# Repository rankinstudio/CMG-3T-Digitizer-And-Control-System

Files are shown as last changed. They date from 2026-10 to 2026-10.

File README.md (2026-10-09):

# CMG-3T Digitizer And Control System

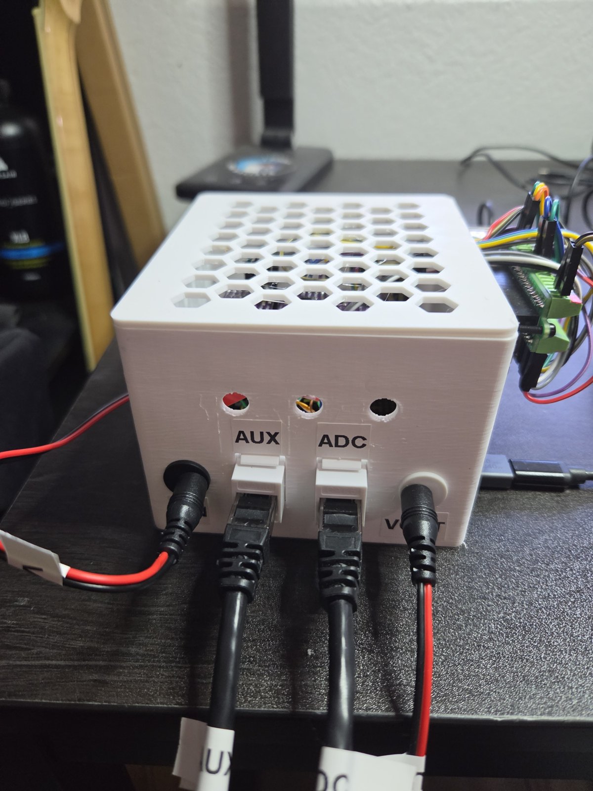
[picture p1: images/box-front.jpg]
The board box: VIN, AUX, ADC and VOUT on the front, the Pi on its side


A three-component digitizer for a Güralp CMG-3T 120 s broadband seismometer:
three ADS1220s for velocity and an ADS1115 for the mass positions, on two
ElectroCookie solderable breadboards, read by a Raspberry Pi 5 that also
locks, unlocks and centres the masses. 0.489 nm/s per count, ±4.1 mm/s full
scale, ~1.5 nm/s/√Hz floor, 100 SPS miniSEED.

**`cmg3t-digitizer.html`** is the build document: block diagram, parts list
with DigiKey numbers, both board layouts hole by hole, the sensor cable table,
the Pi wiring, and the assembly and test stages.
**[Read it here](https://rankinstudio.github.io/CMG-3T-Digitizer-And-Control-System/cmg3t-digitizer.html)** (GitHub's file view shows only
the source).

Companion project: [DIY-SEISMO](https://github.com/rankinstudio/DIY-SEISMO), a
geophone station built the same way; the shared stream format and capture core
come from it.

| Path | What |
|---|---|
| `cmg3t-digitizer.html` | Build document |
| `connector_pinface.png` | The sensor's 26-pin connector, pin letters from the pin face |
| `pi/` | Pi software: capture daemon, mass control, bring-up checks ([README](pi/README.md)) |
| `enclosure/` | 3D-printed box for the boards with the Pi on its side ([README](enclosure/README.md)) |
| `pc/` | PC viewer (Z/N/E traces and spectrograms in three bands) and earthquake plots ([README](pc/README.md)) |

## About the sensor

**History.** Güralp Systems, of Reading in England, launched the 3T in the
mid-1980s: the company dates it to 1985, and it has been in continuous
production since 1987. It was the first field-worthy three-component broadband
feedback seismometer, and more than 3000 have been deployed worldwide. It
became a standard sensor for national seismic networks and for the
instrument pools that lend seismometers to university experiments, above all
the US PASSCAL pool, which also bought cold-rated 3Ts for Antarctica. From 2004
it was one of the three broadband sensors of EarthScope's USArray
Transportable Array, alongside the Streckeisen STS-2 and the Nanometrics
Trillium 240: a grid of about 400 stations, 70 km apart, that rolled across
the lower 48 states from 2004 to 2015 (1679 sites in all), then Alaska and
western Canada until 2021.

**Retirement.** The Transportable Array closed in 2021 and the pools now field
newer designs, so many older 3Ts, typically 1990s and 2000s builds, have been
retired and turn up on the surplus market, usually without their cables. This
one, serial T35286, is ex-PASSCAL: pier tests at the instrument center in
Socorro from 2008, deployments in South Carolina (2013–2014) and at Tok in
interior Alaska (2016–2018, 26 months), and a last pier test in October 2018.
Its Alaska data, which are public, show all three components healthy at both
ends of that deployment and the centring motors still working ten weeks before
it came out.

**Performance.** Force feedback holds the masses still and reads the force
needed to do it, so one instrument covers the whole seismic band with a single
transfer function:

| | |
|---|---|
| Response | Flat to velocity, 120 s – 50 Hz (360 s and other corners were options) |
| Sensitivity | 2 × 750 V/(m/s), differential |
| Clip | ±10 V per side, ±20 V differential: about 13 mm/s |
| Self-noise | Below the USGS New Low Noise Model from beyond 200 s to 20 Hz (vertical) |
| Dynamic range | Over 140 dB across the passband; linearity >111 dB vertical, >107 dB horizontal |
| Mass control | Remote lock, unlock and centre; masses recentre over ±2.5° of tilt |
| Power | 10–36 V DC, ~62–75 mA at 12 V, more while the motors run |

In practice that range spans the Earth's quietest ground motion at long
periods, the ocean microseism at 3–20 s, the surface waves of distant
earthquakes at 20–100 s and more, and local events up to about 13 mm/s. The
vertical is the quiet component at long period; the horizontals also respond
to tilt, so in a shallow or thermally unstable vault they sit well above the
vertical below ~20 s. This digitizer clips at ±4.1 mm/s and its own floor,
~1.5 nm/s/√Hz, is below the low-noise model from 0.01 to ~0.7 Hz: the band where
the sensor is quietest.

Sources: Güralp, [About us](https://www.guralp.com/about-us) and
[CMG-3T datasheet](https://nappe.wustl.edu/SPREE/instrument-other-documentation/from-Guralp/CMG-3T-datasheet.pdf);
EarthScope Primary Instrument Center, [polar sensors](https://epic.earthscope.org/content/polar/equipment/year-round/sensors)
and [sensor comparison](https://epic.earthscope.org/content/instrumentation/sensors/sensor-comparison-chart);
USArray, [when and where](http://www.usarray.org/public/about/when) and
[the Alaska Transportable Array](http://www.usarray.org/Alaska); the unit's
history from PASSCAL station metadata (EarthScope FDSN web services) and its
TOK4 waveforms.

## Cost

Approximate, in US dollars, before shipping and tax. Part numbers are in the
build document's parts list.

| Item | Where | Cost |
|---|---|---|
| Güralp CMG-3T 120 s, used ex-pool unit (no cable) | eBay / surplus | $160 |
| Raspberry Pi 5 (4 GB), 27 W USB-C supply, active cooler, 32 GB microSD, right-angle USB-C adapter | any Pi reseller | $97 |
| ADS1220 modules ×3 (plus a spare), ADS1115 breakout | AliExpress / Amazon | $33 |
| ElectroCookie solderable breadboards (pack of 3) | Amazon | $10 |
| Board parts: 0.1 % divider resistors, film and ceramic caps, LM4040 reference, sockets, optocouplers, Schottky, 1 % resistors | DigiKey | $28 |
| Cat6 keystone jacks ×2, stranded patch cables ×2, two-core power lead, Dupont leads | Amazon | $30 |
| Panel DC jacks ×2 and a plug, panel buttons ×3, standoffs and nuts | Amazon | $20 |
| 12 V 1 A DC adapter | Amazon | $8 |
| Filament for the box (~130 g) | — | $3 |
| **Total** | | **≈ $390** |

Without the sensor it is about $230; with a Pi already on hand, about $130.
The sensor dominates, and used 3T prices vary: check a unit's history before
buying (its serial number in public station metadata).

## Skills required

None of it is advanced, but all of it gets used:

- **Through-hole soldering** on a solderable breadboard: 37 parts and about 34
  insulated jumpers and bus wires across two boards, header strips cut to length, short
  wires soldered straight into holes. A fine tip and a steady hand; no
  surface-mount work (the converters come on modules).
- **A multimeter**: resistance (telling 4.99 k from 10 k 0.1% parts before
  they go in, cold checks for shorts), DC volts (supply rails, the 2.5 V
  reference, the 12 V path) and continuity, to buzz out every conductor of the
  sensor harness. The build document names the mode and range for each step.
- **Wiring and cabling**: Dupont sockets on the sensor's pins, punching down
  Cat6 keystone jacks to T568B with a punch-down tool, panel DC jacks.
- **3D printing**: three parts with no supports. Expect to tune two clearances
  for your printer (the lid fit and its snap bumps); the fit-test plate checks
  the wall openings first.
- **Raspberry Pi and Linux**: flash Raspberry Pi OS, work over SSH, edit
  `/boot/firmware/cmdline.txt`, set up a Python venv and a systemd service.
- **Python on a PC**: install packages with pip, run scripts from a terminal,
  edit a JSON settings file.
- **Handling the sensor**: it weighs 14 kg and has locked masses. Level it with
  its feet and bubble, and lock it before it is ever moved.

Tools: soldering iron and solder, flush cutters, wire strippers, multimeter,
punch-down tool, 3D printer, a small nut driver or pliers for the standoff nuts.

## Order of work

1. Build and test the ADC board, then the AUX board (build document, stages 1–2).
2. Print the fit test, then the box; fit the boards and the Pi (stage 3).
3. Pi: Raspberry Pi OS, `pcie_aspm=off`, the capture service (`pi/README.md`).
4. Sensor: harness buzzed out, connect it locked, power, unlock on its final
   pad (stage 4). Allow ~4 hours of settling.

## Earthquake plots on the PC

`watch_cmg.py` polls the USGS catalogue for M > 4 quakes, waits until their
waves have reached the Pi's disk, and runs `cmgevent.py <usgs id>`, which saves
Z/N/E plots in the viewer's three bands (0.5–2 Hz, 0.02–1 Hz, 0.01–0.1 Hz) when
the quake shows above the noise on Z. Set `stationLat` / `stationLon` in
`pc/cmg3t.JSON` first. Any quake by hand: `python cmgevent.py us6000tz62`.

## Photos

| | |
|---|---|
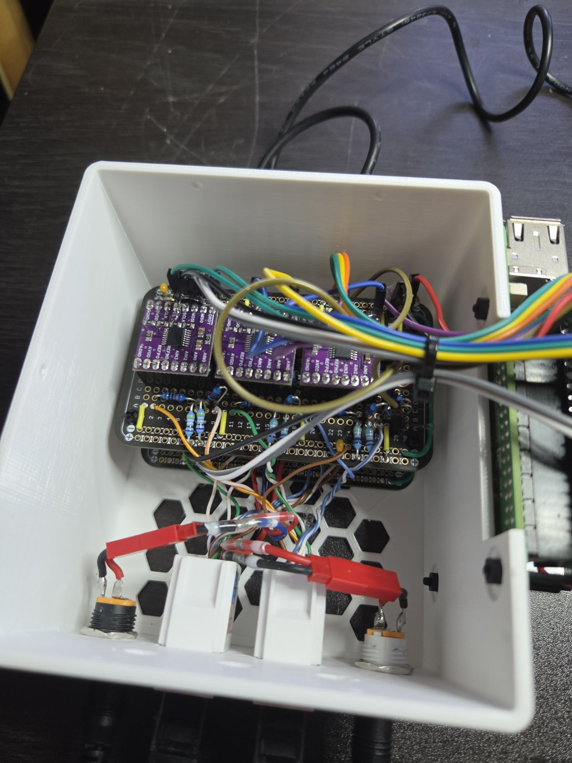
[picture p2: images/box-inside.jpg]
Inside the box
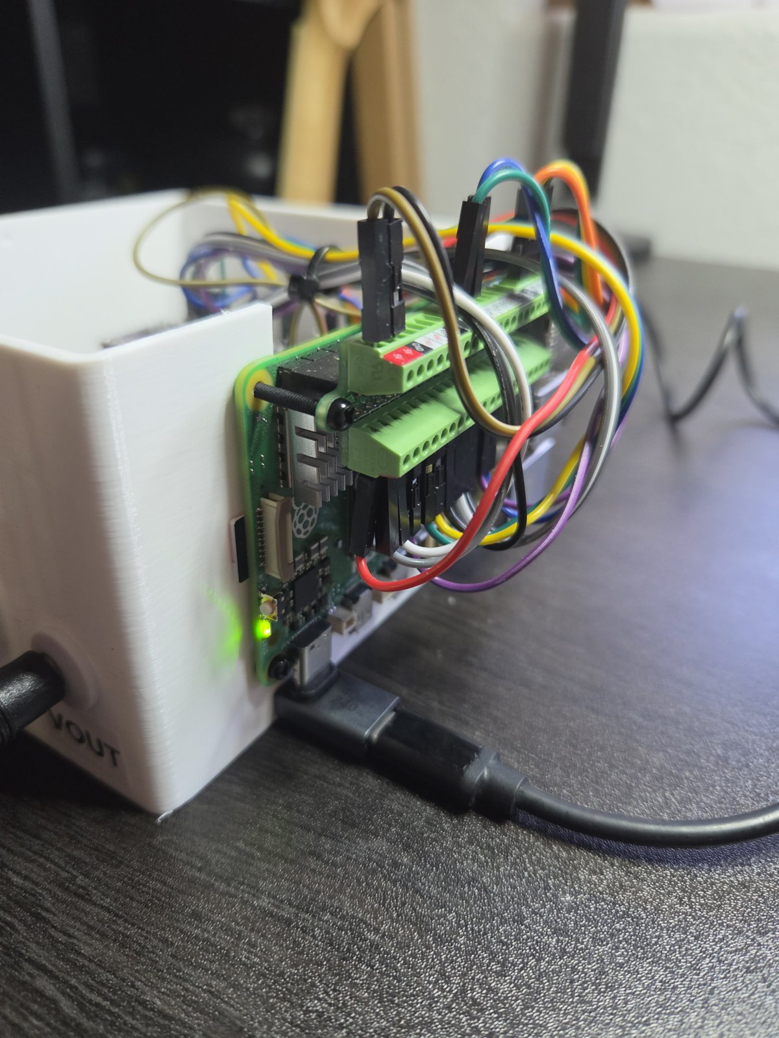
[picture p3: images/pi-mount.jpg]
The Pi on the side wall
|  |  |
| Inside: ADC board above the AUX board; keystones and DC jacks on the front wall | The Pi 5 on the side wall, GPIO wires over the top |
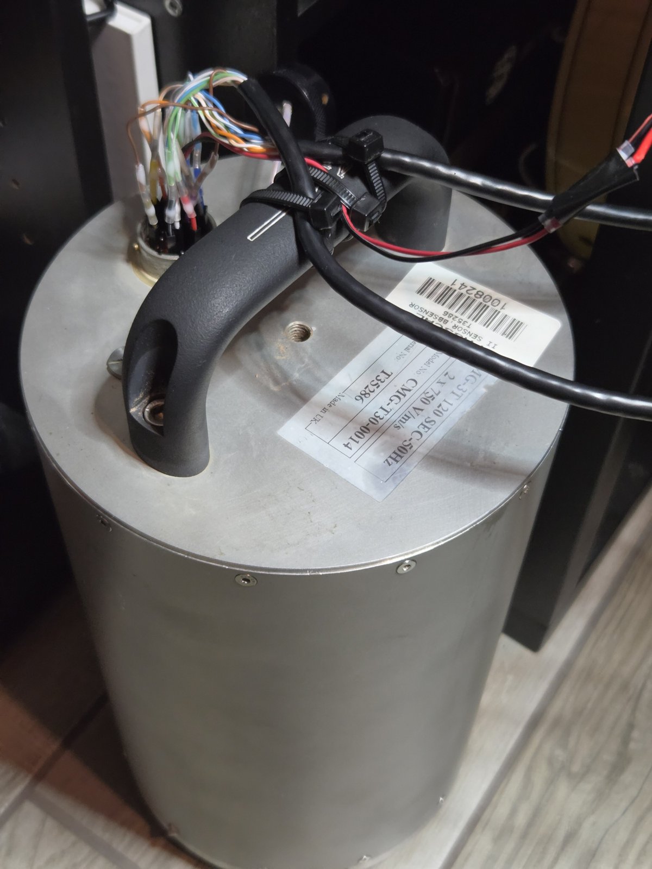
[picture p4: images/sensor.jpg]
The sensor
|  | |
| The CMG-3T: Dupont sockets on its pins, the two Ethernet cables and the power lead | |

## Example: M7.7 Panama, 2026-10-09

USGS us6000u18k, 12 km WSW of Pitaloza Arriba, Panama, 17:56:06 UTC, 13 km deep.
4,136 km from the station (37.2°), arriving from azimuth 125° (SE).
Predicted arrivals: P 18:03:16, S 18:09:04, Rayleigh waves from about 18:13 UTC.
The largest ground velocity was 0.49 mm/s, well inside the 4.1 mm/s full scale,
so nothing clipped. Against the 15 min before P, the quake is 29 times louder in
the short-period band and over 1,000 times louder in the 1–50 s and 10–100 s bands.

The plots are made by `pc/cmgwaves.py` from the saved data. N and E are rotated
to **R** (radial: along the path from the quake) and **T** (transverse: across
it), so each wave type lands on its own component. Times are minutes after the
origin. Thin white lines are the predicted body waves: **P** and **S** take the
direct path through the mantle; **PP**, **SS** and **SSS** bounced once or twice
off the surface on the way, so they arrive later. The coloured spans are the
surface waves, placed by their travel speeds over the 4,136 km path; dotted
blue lines are the P waves of aftershocks (M5.0–5.8) arriving during the window.

**10–100 s view (0.01–0.1 Hz).** P (7 min) is small at these periods; S
(13 min) is clearer, mainly on R. **Love waves** (purple) start at about 15 min
on T only: they move the ground side to side, which Z never sees. **Rayleigh
waves** follow on Z and R, which they move together in a rolling motion: first a
few long-period swings (yellow), then the dense, regular train (red). After
about 28 min the **coda** (grey) is surface-wave energy scattered along the way,
dying out over the next half hour. The first aftershock's P lands at 33 min.

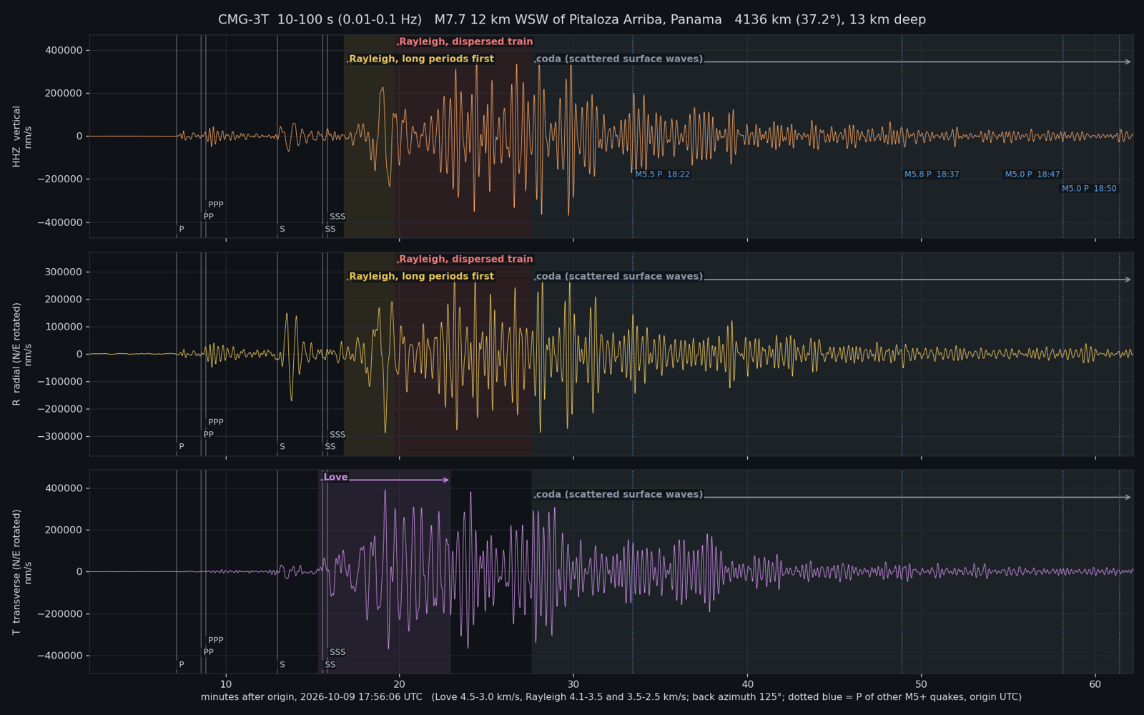
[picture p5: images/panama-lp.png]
Labelled traces, 10-100 s view


**Spectrogram of the same hour,** Z above and T below; brighter means more power
at that period. This shows *why* the waves change shape: surface waves are
dispersive. Long periods reach deeper into the faster mantle and arrive first;
shorter periods travel in the slower crust and arrive later. The bright streak
on T (Love) starts near 60 s at about 17 min and slides down to about 20 s by
30 min. The same falling curve appears on Z (Rayleigh) a couple of minutes later,
because Rayleigh waves travel a little slower than Love waves.

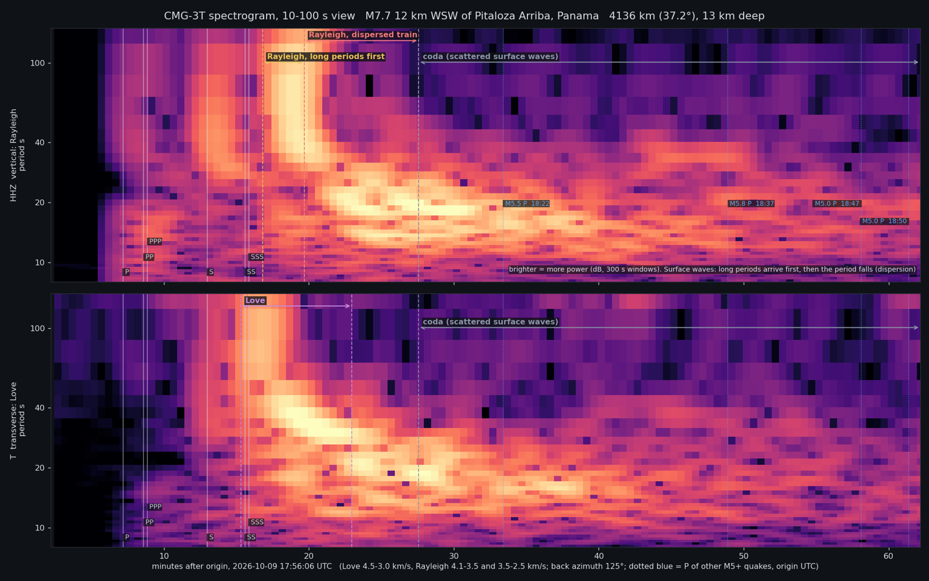
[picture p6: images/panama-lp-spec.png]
Labelled spectrogram, 10-100 s view


**1–50 s view (0.02–1 Hz),** the first 35 min. The body waves are sharper here:
P and PP at 7–9 min on Z and R, S at 13 min. The surface waves are the same
sequence as above, now with their shorter periods included.

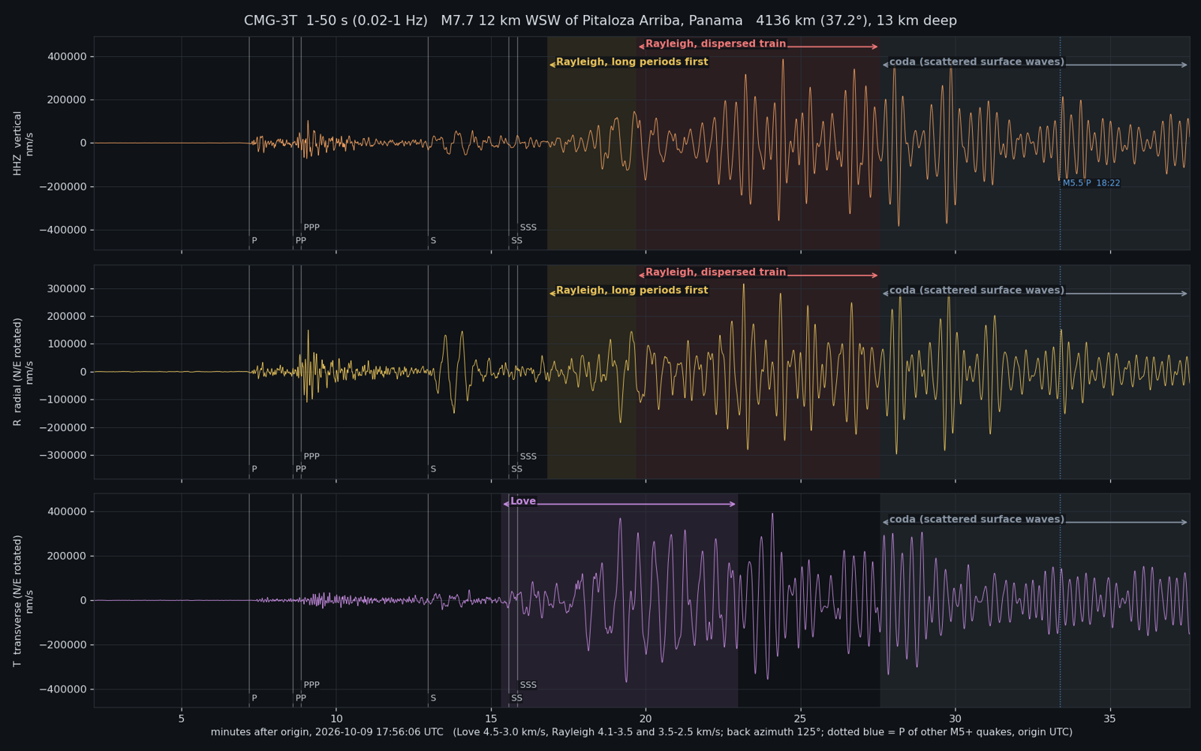
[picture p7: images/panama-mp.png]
Labelled traces, 1-50 s view


**Spectrogram, 1–50 s view.** P and PP put their energy at 2–8 s periods; the
surface waves take over at 15–40 s from about 16 min and dominate the rest of
the window.

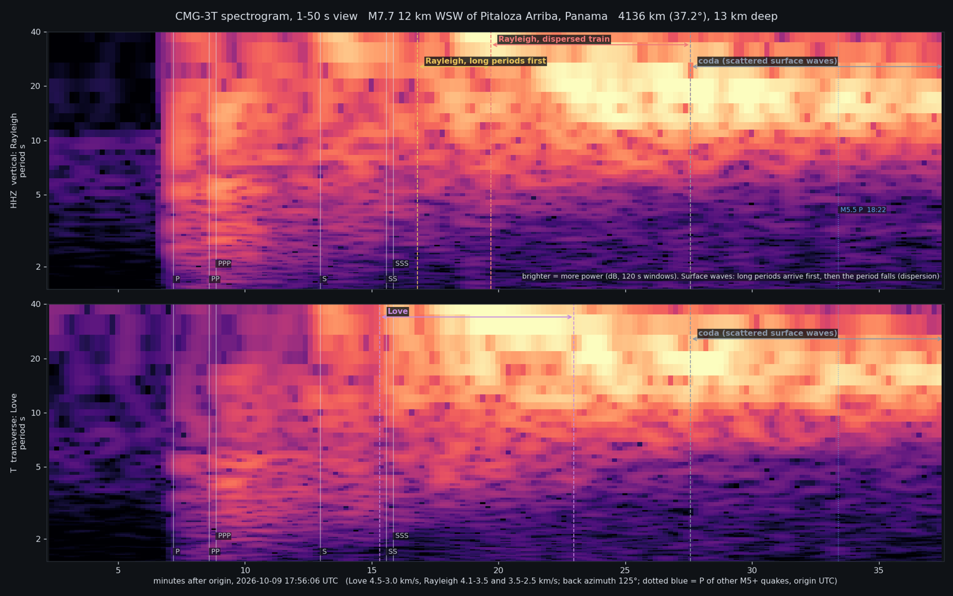
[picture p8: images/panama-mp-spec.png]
Labelled spectrogram, 1-50 s view


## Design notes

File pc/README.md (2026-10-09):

# PC software

Python 3 with `numpy`, `scipy`, `matplotlib`, `obspy` and `python-telegram-bot`; `ssh`/`scp` with a key
to the Pi (`serverIP` in `cmg3t.JSON`, user `david` in `cmgevent.py`).

- `cmgclient.py` (settings `cmg3t.JSON`): live Z, N, E traces with spectrograms,
  in three views:

  | view | band | window | shows |
  |---|---|---|---|
  | short period | 0.5–2 Hz | 15 min | local and regional P and S, traffic |
  | 1–50 s | 0.02–1 Hz | 1 h | the ocean microseism, regional quakes |
  | 10–100 s | 0.01–0.1 Hz | 1 h | surface waves of distant quakes, below the microseism |

  Options: a host name or address; `--fresh` (ignore the Pi's replay, start
  empty); `--mp` or `--lp` (start in the 1–50 s or 10–100 s view); `--spec ZNE`
  (spectrograms for these components; `Z` is the default, `none` for traces only).
  Keys in the plot window:

  | key | does |
  |---|---|
  | `l` | next view: short period → 1–50 s → 10–100 s → short period |
  | `c` | clear the display and start again from the next block |
  | `s` | save the window as a PNG |
  | `f` | full screen on / off |
  | `g` | grid on / off (axes under the mouse) |
  | `q` | close |

  Each view's band, window length, decimation and spectrogram settings are in
  `cmg3t.JSON`: the top level is the short-period view, `midPeriod` and
  `longPeriod` override it for the other two.

  Earthquake alert (`cmgalert.py`, `alert` and `telegram` in `cmg3t.JSON`, same
  names and meanings as rsudp's): a recursive STA/LTA on Z (15 s / 140 s,
  0.01–2 Hz after rsudp's 0.1–0.6 Hz velocity pre-filter) triggers once it has
  stayed above `threshold` (2.4) for `duration` (32 s), and resets below `reset`
  (1.6). As in rsudp the ratio starts from zero at the start of its 140 s
  window, so steady noise reads ~1.6, not 1. Each trigger posts a Telegram
  message, draws a blue start line (red at reset) on the traces, and saves the
  views in `screenshot_views` (`SP`, `MP`, `LP`; default short period and
  1–50 s) to `cmg3t/alerts/`, whichever view is on screen, sending each PNG to
  the same chat. Each is saved once the event is `save_pct` (0.7) across that
  view's window: short period 10.5 min after the trigger, 1–50 s 42 min after,
  late enough for a distant quake's surface waves. It runs in
  every view; the title shows the current ratio, the timer while it runs, and
  the trigger count. Needs `pip install python-telegram-bot`.
- `cmgevent.py <usgs id>`: pulls the hours around a catalogued quake from the
  Pi, band-passes Z/N/E in those three bands, and saves the plots under
  `cmg3t/events/<origin>_M<mag>_<place>/` if the quake registered: Z louder,
  where that band's waves should arrive, than 2× anything in the 15 min before
  P. A quake whose window holds the waves of one that should be louder at the
  station is reported as masked. `--force` saves the plots regardless.
- `cmgwaves.py <usgs id>`: dark plots of one quake in the 1–50 s and 10–100 s
  bands, Z with N/E rotated to radial and transverse, every wave type labelled
  (P, PP, S, SS, SSS, Love, Rayleigh, coda, other quakes' P), plus a labelled
  Z / transverse spectrogram per band, into the same event folder. Uses the data
  `cmgevent.py` already pulled; `--pull` fetches it from the Pi first.
- `watch_cmg.py`: polls the USGS catalogue every 5 min for M > 4 and runs
  `cmgevent.py` for each once its waves have reached the Pi (up to ~2 h).
  Log to a file and leave it running, e.g. on Windows:

```powershell
New-Item -ItemType Directory -Force cmg3t\events | Out-Null
Start-Process python -ArgumentList '-u','-W','ignore','watch_cmg.py' -WindowStyle Hidden -RedirectStandardOutput cmg3t\events\watch.log -RedirectStandardError cmg3t\events\watch.err
```

Set `stationLat` / `stationLon` in `cmg3t.JSON` before using either.

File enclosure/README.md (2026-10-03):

# Enclosure

A printed box for the ADC/AUX board stack, with the Raspberry Pi 5 on its
right-hand wall. Outside 101 × 112 × 74 mm (base) plus an 8 mm lid; 2.5 mm walls.

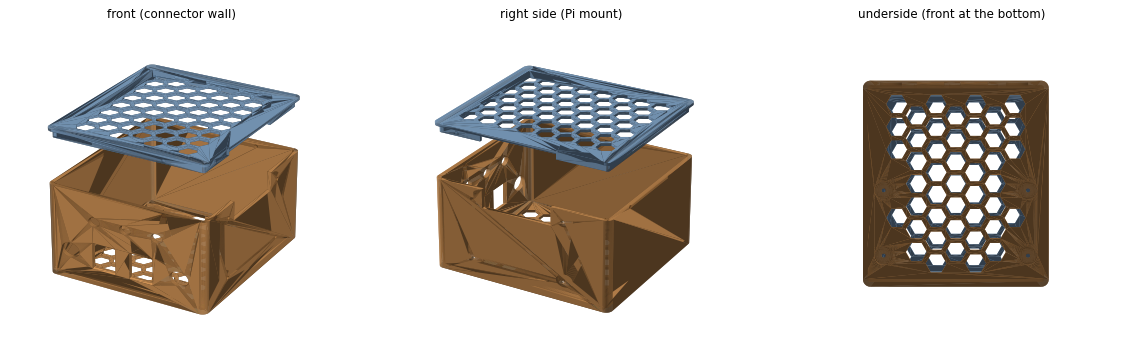
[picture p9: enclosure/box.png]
box


| File | What |
|---|---|
| `box_base.stl`, `box_lid.stl` | The box |
| `fit_test.stl` | One keystone, DC jack and button opening on a 2.5 mm plate: print this first |
| `box.py` | Generates both STLs and `box.png`, `box_floor.png` (all dimensions are settings at the top) |
| `parts.py` | Keystone socket and jack hole geometry, shared by `box.py` and `fit_test.py` |
| `fit_test.py` | Generates `fit_test.stl` |
| `pi_mount_view.py` | Renders a rough Pi 5 on the wall (`pi_mount.png`) to check the mount |

**Front wall**, left to right: VIN jack (12 V adapter in), AUX keystone (CTL),
ADC keystone (SIG), VOUT jack (the sensor's power lead), and the
LOCK / UNLOCK / CENTRE buttons above (7 mm). Keystones snap in from inside,
latch up.

**Floor:** four 14 mm pads under the board's corner holes (78.7 × 35.6 mm).
M2 standoffs with a 4 mm stud stand on them, the stud through the floor and a
nut from below in a 10 mm pocket; the stud ends flush with the bottom.

**Pi mount:** the same standoffs through the right wall (Pi 5 hole pattern
58 × 49 mm), nuts inside. Component side out, GPIO header at the top: the
wires go over the board's top edge into an open-topped slot, which the lid
closes. USB/Ethernet face the back; USB-C faces down, 12 mm above the table,
so use a right-angle adapter.

**Floor and lid** are honeycombed (10 mm hexes). The lid's inner lip has six
bumps that click into dimples in the walls; it fits one way round, with its
lip gap over the Pi slot. `LIP_GAP` (0.05 mm) and `DET_H` (0.4 mm) set how
tight; adjust for your printer.

**Printing:** base upright, open side up, no supports; lid flat face down;
fit test outer face down. Requires `numpy`, `trimesh`, `shapely`,
`matplotlib` to regenerate.

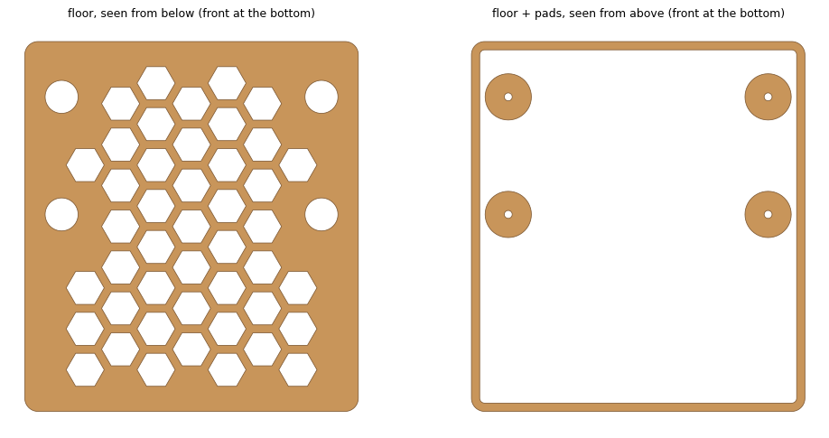
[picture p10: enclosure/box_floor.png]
floor

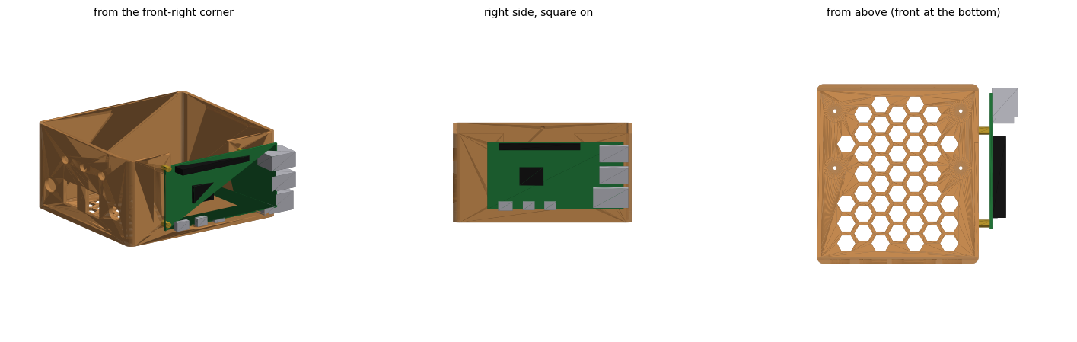
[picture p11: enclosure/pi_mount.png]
pi mount


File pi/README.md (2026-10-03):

# CMG-3T station software (Raspberry Pi 5, `~/cmg3t`)

| File | What |
|---|---|
| `cmgcapture.py` | Capture daemon: 3 × ADS1220 → 100 SPS on the UTC grid → miniSEED + TCP; mass positions at 1 SPS |
| `cmgctl.py` | `mass [secs]`, `lock`, `unlock`, `centre`: 7 s pulse on the optocoupler, then watches the masses |
| `config.JSON` | Station identity, ports, log retention |
| `cmgcapture.service` | systemd unit |
| `aux_check.py`, `ads_check.py`, `ads_noise.py` | Bring-up checks |
| `geocapture.py`, `geostream.py`, `loadOpts.py` | Shared core from DIY-SEISMO: timing, miniSEED writer, network, settings |

Copy the whole folder to `~/cmg3t` on the Pi. Python: a venv with system site packages plus
`obspy` and `smbus2` (`gpiod` and `spidev` come with Raspberry Pi OS).

## Pi 5: turn PCIe ASPM off

Append ` pcie_aspm=off` to the single line in `/boot/firmware/cmdline.txt` and
reboot. With ASPM on, the PCIe link to the RP1 (the chip behind the GPIO and SPI
pins) drops into L1 between reads and puts an ~80 ms disturbance on all three
channels every 2.77 s. Check: `cat /proc/cmdline` shows `pcie_aspm=off`.

## Running

    sudo cp cmgcapture.service /etc/systemd/system/
    sudo systemctl daemon-reload
    sudo systemctl enable --now cmgcapture
    journalctl -u cmgcapture -f

It waits for NTP before it starts logging. Stop it before `ads_check.py` or
`ads_noise.py`; `cmgctl.py` and `aux_check.py` run alongside it.

## Mass control

    python3 cmgctl.py mass        # positions once; centred is within ±2 V, locked ±8 V
    python3 cmgctl.py unlock      # only level, on the final pad
    python3 cmgctl.py centre      # if a mass settles beyond ±2 V
    python3 cmgctl.py lock        # before moving it. Never move it unlocked

Each command takes a few minutes of audible motor activity. After unlocking,
allow about 4 hours of settling before trusting the long-period band.

## Output

- `~/cmg3t/data/YYYY/YYYYMMDD/XX.QUAK..HH{Z,N,E}.YYYYMMDD_HH.mseed`: FLOAT32 nm/s,
  exactly 100 SPS, raw (no DC block or high-pass)
- `...LM{Z,N,E}...mseed`: mass positions, volts, 1 SPS
- TCP, GEO1 format: Z 1244, N 1245, E 1246; the last hour is replayed on connect
- Pruned at 365 days / 40 GB

## Status line (journal, every 10 s)

`150.00 SPS  seg 0  missed 0  late 0 (max 0.01 ms)  clients 3  queued 0  peak … nm/s  mass +0.11 -0.71 +0.28 V`

- seg: timing segments; a new one is a stall or clock step (a gap in the data)
- missed / late: conversions not read in time, filled by interpolation
- peak: largest |velocity| in the last 10 s per component
- mass: a warning is logged past ±2.5 V (centre) or ±7 V (on the stops)

## Troubleshooting

- All three masses read the same value (e.g. +0.67 V) and the three velocity
  channels wander together: the sensor has no power. Check its two-core lead
  (c / b) and the VIN / VOUT jacks.
- All three masses read about +2.5 V (the open-input value): the CTL cable is
  not plugged in.

## Viewing on a PC

    python cmgclient.py            # Z/N/E traces + spectrograms; l cycles the views

From `../pc`; settings in `pc/cmg3t.JSON`.

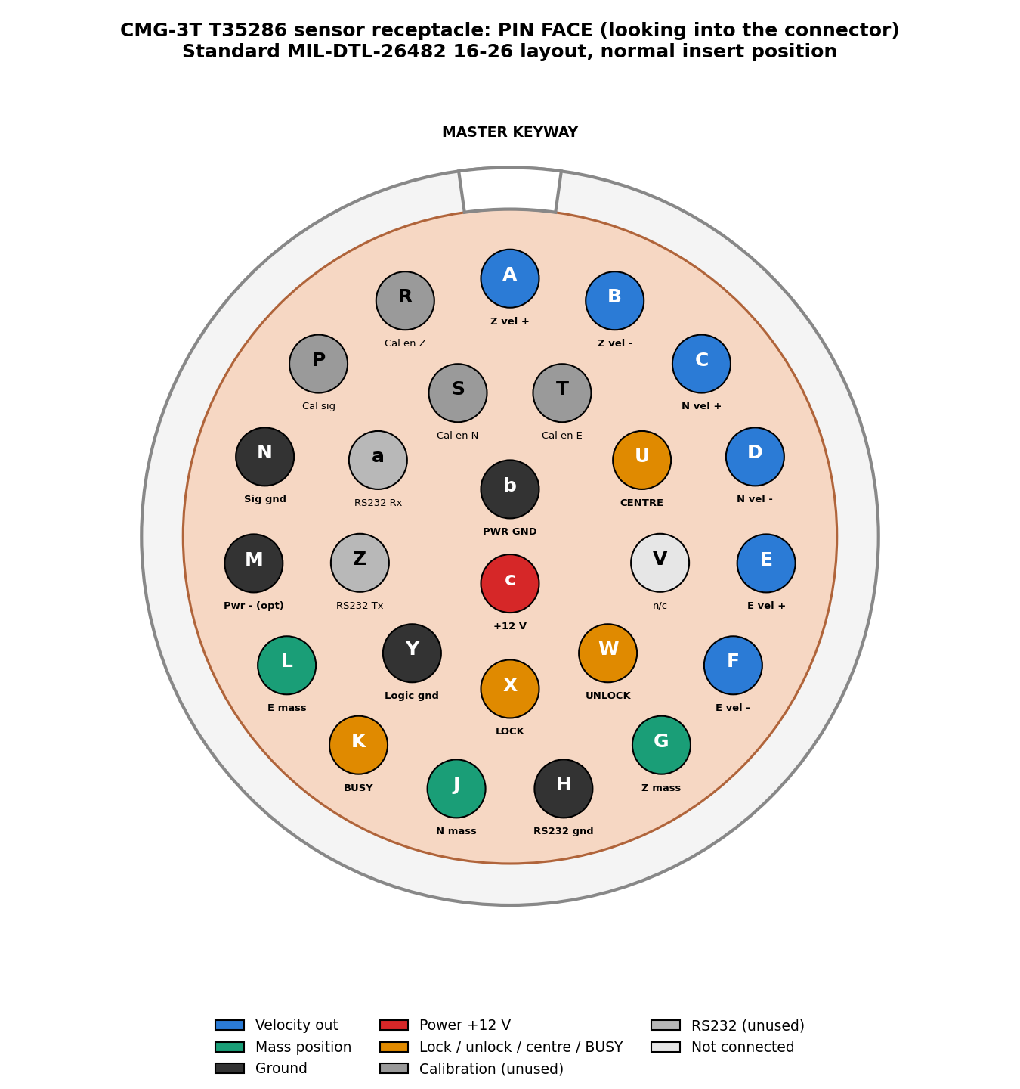
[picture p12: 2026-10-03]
connector_pinface.png

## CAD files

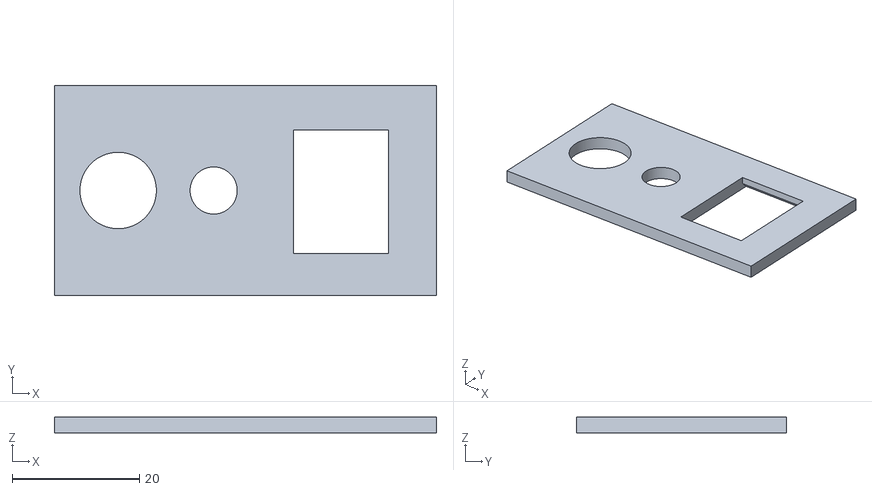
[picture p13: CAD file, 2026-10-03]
enclosure/fit_test.stl
60.0 x 33.0 x 2.50

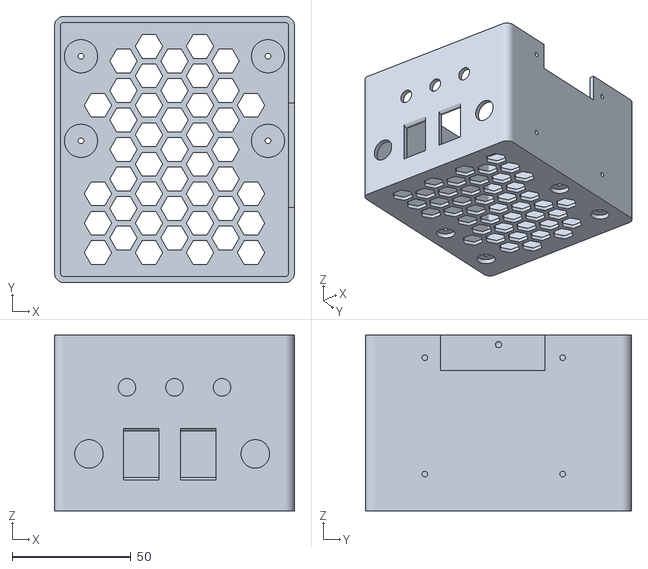
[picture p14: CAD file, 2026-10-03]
enclosure/box_base.stl
101.0 x 112.0 x 74.0

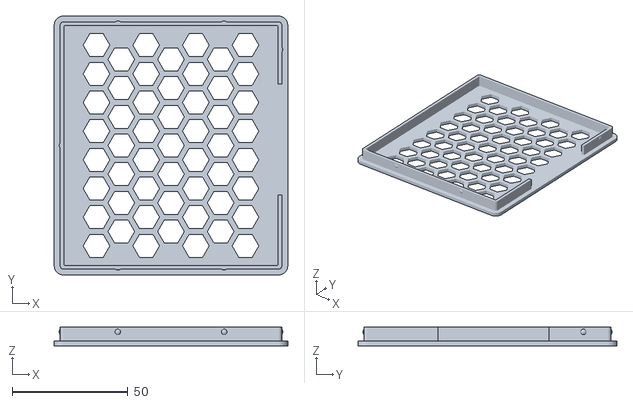
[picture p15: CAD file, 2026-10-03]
enclosure/box_lid.stl
101.0 x 112.0 x 8.00

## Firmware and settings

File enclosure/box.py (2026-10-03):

#!/usr/bin/env python3
"""CMG-3T board box: base + snap-on lid for the ADC/AUX ElectroCookie stack.

    python box.py               # writes box_base.stl, box_lid.stl, box.png, box_floor.png here

Board: ElectroCookie half-size, 88.9 x 52.1 mm; the stack stands on its M2
corner holes, 78.7 x 35.6 mm centre to centre. The bottom standoffs have a
2 mm threaded stud, 4 mm long: each stands on a short floor pad, the stud goes
down through it and a nut (6 mm) goes on from under the box, sunk into a 10 mm
pocket. Pad + floor is 4 mm, so the stud ends flush with the bottom.

Front wall (y = 0, a long side), left to right from outside: VIN jack (12 V in),
AUX keystone (CTL), ADC keystone (SIG), VOUT jack (sensor power lead), and
above them the LOCK / UNLOCK / CENTRE buttons (7.4 mm holes). Keystone
sockets (parts.py) take Cat6 keystone jacks latch side up, snapped in from
inside; ~49 mm from the front wall to the boards clears the jacks'
punch-down ends and cables.

Right side wall (x = IN_L, seen from the front): the Raspberry Pi 5 mounts on
the outside, on the same stud standoffs as the board (stud in from outside, nut
inside in a 10 mm pocket that thins the wall to 1.5 mm). Pi long side
horizontal, component side out: GPIO header along the top edge, USB/Ethernet
end towards the back, USB-C and HDMI along the bottom edge (12 mm above
the table, so a right-angle USB-C plug). The wires go over the Pi's top edge
into an open-topped slot in the wall, closed off by the lid.

Floor and lid carry a honeycomb of hex holes to save plastic. The lid's inner
lip has six bumps that click into dimples in the base walls; the lid fits one
way round, with its lip gap over the Pi slot.

fit_test.py prints one of each wall opening on a small plate: check the
keystone, DC jack and button fit before printing the box.

Print the base upright (open side up), no supports: the keystone openings bridge
14.9 mm. Print the lid top-down (flat face on the bed).
"""
import os

import numpy as np
import trimesh
from trimesh.creation import box, cylinder

from parts import at, keystone_void, jack_hole, KS_W, KS_H, KS_D, JACK_HOLE

HERE = os.path.dirname(os.path.realpath(__file__))

# ------------------------------------------------------------------ settings --
WALL = KS_D                               # 2.5: keystones cut straight into the wall
FLOOR = 2.0
IN_L, IN_W, IN_H = 96.0, 107.0, 72.0     # inside: length (x), width (y, front to back), height (z)
CORNER_R = 4.0                            # outside corner radius (vertical edges)

BOARD_L, BOARD_W = 88.9, 52.1
HOLE_DX, HOLE_DY = 78.7, 35.6             # M2 corner holes, centre to centre
BOARD_BACK_GAP = 6.0                      # board edge to the back wall
POST_H, POST_D = 2.0, 14.0                # pad under each standoff (covers the nut pocket); FLOOR + POST_H = 4 = stud length
SCREW_D = 2.4                             # clearance for the 2.2 mm stud
NUT_D, NUT_H = 10.0, 2.5                  # nut pocket under the floor; leaves 1.5 mm clamped. Room to
                                          # turn a 6 mm nut (6.9 across corners) with a driver

CONN_Z = 22.0                             # connector centre height above the floor (inside)
#   x positions (inside, from the left inner wall) of the front-wall connectors
CONNECTORS = [('jack', 12.0), ('keystone', 34.0), ('keystone', 58.0), ('jack', 82.0)]

# LOCK / UNLOCK / CENTRE panel buttons, a row above the connectors on the front
# wall; x from the left as seen from OUTSIDE (same as the connectors)
BUTTON_D, BUTTON_Z = 7.4, 50.0               # 7 mm panel buttons
BUTTONS = [('LOCK', 28.0), ('UNLOCK', 48.0), ('CENTRE', 68.0)]

# Raspberry Pi 5 on the outside of the right wall. Pi board 85 x 56, M2.5 holes
# 58 x 49 apart, 3.5 mm in from the edges at the end away from USB/Ethernet.
PI_L, PI_W = 85.0, 56.0
PI_HOLE_DX, PI_HOLE_DY, PI_HOLE_IN = 58.0, 49.0, 3.5
PI_Y0 = IN_W - 88.0                       # board's front (holes) end, inside y; ports (88 incl. overhang) end at the back wall
PI_TOP = 66.0                             # board's top edge, inside z coordinate (base rim at IN_H = 72)
PI_STUD_D = SCREW_D                       # same 2 mm stud standoffs as the floor
PI_NUT_D, PI_CLAMP = NUT_D, 1.5           # nut pocket from inside; wall left under the standoff
PI_SLOT_Y = (PI_Y0 + 10.0, PI_Y0 + 54.0)  # wire slot behind the GPIO header (header runs ~7..58 from the holes end)
PI_SLOT_DEPTH = 15.0                      # from the top edge of the wall

# honeycomb cut-outs in the floor and lid to save plastic: hexes this far across the
# flats, ribs this wide, kept clear of the walls and the standoff pads
HEX_AF, HEX_RIB = 10.0, 2.4
HEX_WALL_MARGIN = 4.0                     # solid floor along the inside of the walls
HEX_PAD_CLEAR = 9.5                       # solid floor this radius around each standoff (pad is 7)

LID_T = 2.0
LIP_H, LIP_T, LIP_GAP = 6.0, 1.6, 0.05    # lid's inner lip: height, thickness, clearance per side (snug)

# snap detents: round bumps on the outside of the lid's lip click into dimples in
# the base's inner walls. Bump h proud of the lip, dimple d deep, both on spheres
# of radius R, DET_DOWN below the base rim (2 mm above the lip's free edge, where it flexes)
DET_R, DET_H, DET_D, DET_DOWN = 2.0, 0.4, 0.5, 4.0
#   (wall, position along it): front / back walls by x, left / right by y. The right
#   one sits in front of the Pi wire slot, clear of the Pi's nut pockets.
DETENTS = [('front', 25.0), ('front', 71.0), ('back', 25.0), ('back', 71.0),
           ('left', IN_W / 2), ('right', 12.0)]


# ---------------------------------------------------------------- helpers --
def rounded_box(l, w, h, r):
    """Box with rounded vertical edges, corner at the origin, z from 0 to h."""
    from shapely.geometry import box as sbox
    poly = sbox(r, r, l - r, w - r).buffer(r, resolution=16)
    return trimesh.creation.extrude_polygon(poly, h)


def along_x(d, x0, x1, y, z):
    """Round hole of diameter d along x, from x0 to x1, centred on (y, z)."""
    c = cylinder(radius=d / 2, height=x1 - x0, sections=48)
    c.apply_transform(trimesh.transformations.rotation_matrix(np.pi / 2, (0, 1, 0)))
    return at(c, (x0 + x1) / 2, y, z)


def onto_front_wall(mesh_in_wall_coords, x_centre, z_centre):
    """parts.py wall features use x across, y up, z into the box from the outer
    face. Map onto the front wall: x -> x, y -> box z, z -> box y (outer face at
    y = -WALL). That swap is a mirror; the features are symmetric in x so it
    only needs the normals fixed."""
    m = mesh_in_wall_coords.copy()
    v = m.vertices.copy()
    m.vertices = np.c_[v[:, 0], v[:, 2], v[:, 1]]
    m.invert()
    if m.volume < 0:
        m.invert()
    return at(m, x_centre, -WALL, z_centre)


def detent_spheres(r, out_from_face):
    """Spheres of radius r, one per detent, in base coordinates, centred on the
    line DET_DOWN below the rim, `out_from_face` mm outward (into the wall) from
    the inner wall face (negative = towards the box centre)."""
    z = IN_H - DET_DOWN
    faces = {'front': ((0, 0), (0, -1)), 'back': ((0, IN_W), (0, 1)),
             'left': ((0, 0), (-1, 0)), 'right': ((IN_L, 0), (1, 0))}
    out = []
    for wall, pos in DETENTS:
        (fx, fy), (nx, ny) = faces[wall]
        x = pos if wall in ('front', 'back') else fx
        y = pos if wall in ('left', 'right') else fy
        out.append((at(trimesh.creation.icosphere(subdivisions=3, radius=r),
                       x + nx * out_from_face, y + ny * out_from_face, z), (nx, ny), (x, y)))
    return out


def lid_bumps():
    """The lid's bumps, in base coordinates (lid in place): sphere caps DET_H proud
    of the lip's outer face, rooted 0.8 mm into the lip."""
    g, caps = LIP_GAP, []
    for sph, (nx, ny), (x, y) in detent_spheres(DET_R, -g - DET_R + DET_H):
        keep = at(box((6 if nx else 2 * DET_R + 1, 6 if ny else 2 * DET_R + 1, 2 * DET_R + 1)),
                  x + nx * (3 - g - 0.8), y + ny * (3 - g - 0.8), IN_H - DET_DOWN)
        caps.append(trimesh.boolean.intersection([sph, keep]))
    return caps


def pad_xy():
    bx = IN_L / 2
    by = IN_W - BOARD_BACK_GAP - BOARD_W / 2
    return [(bx + sx * HOLE_DX / 2, by + sy * HOLE_DY / 2) for sx in (-1, 1) for sy in (-1, 1)]


def honeycomb(z0, t, pads=True):
    """Hex holes from z0 through thickness t: every hex of the grid that fits whole
    inside the box's inner footprint less a wall margin (and, for the floor, a
    ring round each standoff pad). The grid is centred, so it lines up the same
    on the floor and on the flipped-over lid."""
    from shapely.geometry import Point, Polygon, box as sbox
    from shapely.ops import unary_union
    m = HEX_WALL_MARGIN
    keep = sbox(m, m, IN_L - m, IN_W - m)
    if pads:
        keep = keep.difference(unary_union([Point(x, y).buffer(HEX_PAD_CLEAR) for x, y in pad_xy()]))
    r = HEX_AF / np.sqrt(3)                           # circumradius, flats top and bottom
    pitch_x, pitch_y = 1.5 * r + HEX_RIB * np.sqrt(3) / 2, HEX_AF + HEX_RIB
    hexes = []
    for i in range(-1, int(IN_L / pitch_x) + 2):
        for j in range(-1, int(IN_W / pitch_y) + 2):
            cx = IN_L / 2 + (i - int(IN_L / pitch_x) // 2) * pitch_x
            cy = IN_W / 2 + (j - int(IN_W / pitch_y) // 2 + (0.5 if i % 2 else 0)) * pitch_y
            h = Polygon([(cx + r * np.cos(a), cy + r * np.sin(a)) for a in np.arange(6) * np.pi / 3])
            if keep.contains(h):
                hexes.append(h)
    m3 = trimesh.util.concatenate([trimesh.creation.extrude_polygon(h, t + 1) for h in hexes])
    return at(m3, 0, 0, z0 - 0.5)


def build_base():
    L, W = IN_L + 2 * WALL, IN_W + 2 * WALL
    H = FLOOR + IN_H
    outer = at(rounded_box(L, W, H, CORNER_R), -WALL, -WALL, -FLOOR)
    inner = at(rounded_box(IN_L, IN_W, IN_H + 1, max(0.5, CORNER_R - WALL)), 0, 0, 0)
    adds, cuts = [], []

    # standoff pads: stud through, nut pocket underneath
    for x, y in pad_xy():
            adds.append(at(cylinder(radius=POST_D / 2, height=POST_H + 0.5, sections=48), x, y, (POST_H + 0.5) / 2 - 0.5))
            cuts.append(at(cylinder(radius=SCREW_D / 2, height=FLOOR + POST_H + 2, sections=32), x, y, (POST_H - FLOOR) / 2))
            cuts.append(at(cylinder(radius=NUT_D / 2, height=NUT_H + 0.5, sections=48), x, y, -FLOOR + (NUT_H - 0.5) / 2))

    cuts.append(honeycomb(-FLOOR, FLOOR))

    # front-wall connectors
    for kind, x in CONNECTORS:
        if kind == 'keystone':
            off = (-KS_W / 2, -KS_H / 2, 0)                # centre the block on (x, CONN_Z)
            void = at(keystone_void(), *off)
            cuts.append(onto_front_wall(void, x, CONN_Z))
        else:
            cuts.append(onto_front_wall(jack_hole(WALL + 1), x, CONN_Z))

    # panel buttons
    for _, x in BUTTONS:
        cuts.append(onto_front_wall(jack_hole(WALL + 1, BUTTON_D), x, BUTTON_Z))

    # Raspberry Pi on the outside of the right wall: stud holes, nut pockets, wire slot
    xw = IN_L                                         # inside face of the right wall
    for hy in (PI_Y0 + PI_HOLE_IN, PI_Y0 + PI_HOLE_IN + PI_HOLE_DX):
        for hz in (PI_TOP - PI_HOLE_IN, PI_TOP - PI_HOLE_IN - PI_HOLE_DY):
            cuts.append(along_x(PI_STUD_D, xw - 1, xw + WALL + 1, hy, hz))
            cuts.append(along_x(PI_NUT_D, xw - 1, xw + WALL - PI_CLAMP, hy, hz))
    sy0, sy1 = PI_SLOT_Y
    cuts.append(at(box((WALL * 3, sy1 - sy0, PI_SLOT_DEPTH + 1)), xw + WALL / 2, (sy0 + sy1) / 2,
                   IN_H - PI_SLOT_DEPTH / 2 + 0.5))

    # order matters: hollow the shell first, then add what stands inside it
    # (posts), then cut the holes through everything
    shell = trimesh.boolean.difference([outer, inner])
    body = trimesh.boolean.union([shell] + adds)
    # detent dimples in the inner walls, DET_D deep
    cuts += [sph for sph, _, _ in detent_spheres(DET_R, -DET_R + DET_D)]
    return trimesh.boolean.difference([body] + cuts)


def build_lid():
    L, W = IN_L + 2 * WALL, IN_W + 2 * WALL
    top = at(rounded_box(L, W, LID_T, CORNER_R), -WALL, -WALL, 0)
    g = LIP_GAP
    lip_o = at(rounded_box(IN_L - 2 * g, IN_W - 2 * g, LIP_H, max(0.5, CORNER_R - WALL - g)), g, g, LID_T)
    lip_i = at(rounded_box(IN_L - 2 * g - 2 * LIP_T, IN_W - 2 * g - 2 * LIP_T, LIP_H + 1,
                           max(0.5, CORNER_R - WALL - g - LIP_T)), g + LIP_T, g + LIP_T, LID_T)
    lip = trimesh.boolean.difference([lip_o, lip_i])
    # leave the lip open over the Pi wire slot so the wires pass under the lid. The
    # lid is built lip-up and flipped over x to fit, so the slot's y is mirrored here.
    sy0, sy1 = PI_SLOT_Y
    notch = at(box((LIP_T * 4, sy1 - sy0 + 4, LIP_H + 1)), IN_L - g - LIP_T / 2, IN_W - (sy0 + sy1) / 2,
               LID_T + LIP_H / 2 + 0.5)
    lip = trimesh.boolean.difference([lip, notch])
    top = trimesh.boolean.difference([top, honeycomb(0, LID_T, pads=False)])   # same hexes as the floor
    # detent bumps: built in place on the base, then flipped into lid coordinates
    # (the same turn over x that puts the lid on: y -> IN_W - y, z -> IN_H + LID_T - z)
    flip = trimesh.transformations.rotation_matrix(np.pi, (1, 0, 0), (0, IN_W / 2, (IN_H + LID_T) / 2))
    bumps = [b.copy() for b in lid_bumps()]
    for b in bumps:
        b.apply_transform(flip)
    return trimesh.boolean.union([top, lip] + bumps)


def preview(parts, path):
    import matplotlib
    matplotlib.use('Agg')
    import matplotlib.pyplot as plt
    from mpl_toolkits.mplot3d.art3d import Poly3DCollection
    views = [(25, -60, 'front (connector wall)'), (25, 30, 'right side (Pi mount)'), (-90, -90, 'underside (front at the bottom)')]
    fig = plt.figure(figsize=(15, 5))
    allv = np.vstack([p.vertices for p, _ in parts])
    lo, hi = allv.min(0), allv.max(0)
    span, c = (hi - lo).max(), (hi + lo) / 2
    for k, (el, az, title) in enumerate(views):
        ax = fig.add_subplot(1, 3, k + 1, projection='3d')
        for m, col in parts:
            tri = m.vertices[m.faces]
            shade = 0.35 + 0.65 * np.clip(m.face_normals @ np.array([0.4, -0.6, 0.7]), 0, 1)
            ax.add_collection3d(Poly3DCollection(tri, facecolors=[(col[0] * s, col[1] * s, col[2] * s) for s in shade],
                                                 edgecolor='none'))
        for f, s in zip((ax.set_xlim, ax.set_ylim, ax.set_zlim), c):
            f(s - span / 2, s + span / 2)
        ax.view_init(elev=el, azim=az)
        ax.set_title(title, fontsize=9)
        ax.set_axis_off()
    fig.savefig(path, dpi=95, bbox_inches='tight')


def floor_plan(base, path):
    """Sections through the floor: from below (mirrored, as you'd see it) and
    from above at pad height."""
    import matplotlib
    matplotlib.use('Agg')
    import matplotlib.pyplot as plt
    from shapely.geometry import Polygon
    fig, axs = plt.subplots(1, 2, figsize=(13, 6.5))
    for ax, (z, title) in zip(axs, ((-FLOOR / 2, 'floor, seen from below (front at the bottom)'),
                                    (POST_H / 2, 'floor + pads, seen from above (front at the bottom)'))):
        g = Polygon()
        for e in base.section(plane_origin=[0, 0, z], plane_normal=[0, 0, 1]).discrete:
            g = g.symmetric_difference(Polygon(np.asarray(e)[:, :2]).buffer(0))
        flip = (lambda xs: IN_L - np.asarray(xs)) if z < 0 else np.asarray
        for poly in getattr(g, 'geoms', [g]):
            xs, ys = poly.exterior.xy
            ax.fill(flip(xs), ys, color='#c8955a', ec='#7a5530', lw=0.6)
            for ring in poly.interiors:
                xs, ys = ring.xy
                ax.fill(flip(xs), ys, color='white', ec='#7a5530', lw=0.6)
        ax.set_aspect('equal')
        ax.set_title(title, fontsize=10)
        ax.axis('off')
    fig.savefig(path, dpi=90, bbox_inches='tight')


if __name__ == '__main__':
    base = build_base()
    lid = build_lid()
    for m, name in ((base, 'box_base.stl'), (lid, 'box_lid.stl')):
        assert m.is_watertight, name + " not watertight"
        m.export(os.path.join(HERE, name))
        print("wrote %s: %.1f x %.1f x %.1f mm, %.0f cm3 of plastic"
              % (name, *(m.bounds[1] - m.bounds[0]), m.volume / 1000))
    # preview: lid shown lifted above the base, upside down as it would sit
    shown = lid.copy()
    shown.apply_transform(trimesh.transformations.rotation_matrix(np.pi, (1, 0, 0), (IN_L / 2, IN_W / 2, 0)))
    shown.apply_translation((0, 0, IN_H + 45))
    preview([(base, (0.85, 0.6, 0.35)), (shown, (0.55, 0.7, 0.85))], os.path.join(HERE, 'box.png'))
    floor_plan(base, os.path.join(HERE, 'box_floor.png'))

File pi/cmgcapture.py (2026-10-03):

#!/usr/bin/env python3
"""CMG-3T capture daemon: three ADS1220s + the ADS1115 mass positions -> disk + TCP.

    python3 cmgcapture.py            # real hardware
    python3 cmgcapture.py --no-log   # stream only

geocapture.py (the EG-4.5 station's daemon) provides the timing, the miniSEED
writer, the pruning and the network; this file imports those unchanged
(geocapture.py, geostream.py and loadOpts.py sit next to it on the Pi) and adds:

One clock. The three ADS1220s run single-shot: the Pi starts all three at once
on an exact UTC grid (150 SPS), waits until all three have finished, then reads
all three. No SPI traffic ever overlaps a conversion, and the three channels
sample the same instant, timed by the NTP-disciplined system clock.

Why not free-running: three chips on their own oscillators (a few tenths of a
percent apart), each read the moment it is ready, means SPI reads land during
the other chips' conversions and disturb them. Converting together and reading
after keeps the bus quiet while they convert.

One output grid. A band-limited (Kaiser-windowed sinc) resampler takes the
150 SPS grid to the 100 SPS one, t = k / 100 s. The kernel is also the
anti-alias filter: flat to 35 Hz (+-0.05 %), -6 dB at 40, >85 dB down from 45
Hz up (mains and motor hum), zero phase. No DC block and no notch: the 3T is
flat to 120 s and a high-pass here would eat the band the instrument was
bought for. The ADS1220's own sinc3
droop (~-3 dB at 50 Hz) is not corrected.

Disk. Hourly miniSEED per channel, NET.STA..HHZ/HHN/HHE (FLOAT32 nm/s, 100 SPS
exactly), and the mass positions as LMZ/LMN/LME (FLOAT32 volts, 1 SPS).

Network. GEO1 blocks (geostream.py), one port per component: zPort / nPort /
ePort (1244-1246). geoclient.py works on any one of them; cmgclient.py shows
all three.

The lock / unlock / centre lines (GPIO16/20/21) are NOT touched here; use
cmgctl.py.
"""
import argparse
import math
import os
import queue
import signal
import sys
import threading
import time

import numpy as np

HERE = os.path.dirname(os.path.realpath(__file__))
sys.path.insert(0, HERE)
from loadOpts import load_config
from geostream import pack_block
from geocapture import (log, wait_for_ntp, MSeedWriter, CsvWriter,
                        prune_log, Broadcaster, HAVE_OBSPY, STATUS_EVERY)

# ------------------------------------------------------------------ ADS1220 --
RESET_CMD, START_CMD, POWERDOWN, RDATA = 0x06, 0x08, 0x02, 0x10
RREG, WREG = 0x20, 0x40
CONFIG = (0x01, 0x50, 0x00, 0x00)   # AIN0/AIN1, gain 1, PGA bypassed; turbo DR 010 SINGLE-SHOT; internal 2.048 V
FS_IN = 150.0                       # conversions started per second, on the UTC grid (one takes 5.40 ms)
LATE_WARN = 0.0003                  # a START later than this past its tick counts as late
COMPS = 'ZNE'
PINS = {'Z': (24, 27), 'N': (25, 22), 'E': (5, 6)}   # BCM: (CS, DRDY) = board pins (18, 13) (22, 15) (29, 31)
GPIOCHIP = '/dev/gpiochip0'                         # Pi 5: the RP1 header bank

VREF_ADC = 2.048
SENS = 1500.0                           # V/(m/s), differential, both halves
DIV_GAIN = 4.99e3 / (4.99e3 + 10e3)     # ADC board level shifter
NM_S_PER_COUNT = VREF_ADC / 2 ** 23 / (SENS * DIV_GAIN) * 1e9     # 0.489 nm/s
FULL_SCALE_MM_S = VREF_ADC / (SENS * DIV_GAIN) * 1e3              # 4.1 mm/s

# ------------------------------------------------------------------ ADS1115 --
MASS_ADDR = 0x48
MASS_CHAN = (('Z', 0), ('N', 1), ('E', 2))     # A3 = VREF
MASS_WARN_V = 2.5                               # |mass| beyond this: suggest CENTRE
MASS_STOP_V = 7.0                               # beyond this: on the stops (locked or fallen)

FS_OUT = 100.0


class TriADS1220:
    """Three ADS1220s on SPI0, single-shot, converted together, read together.

    CS and DRDY through libgpiod (the Pi 5's RP1 bank). DRDY is only looked at
    as a level, once all three conversions should be done: any SPI read on the
    shared bus sends the other modules' DRDY high again (the data register
    is intact), so nothing is read until all three are low."""

    def __init__(self, speed=1_000_000):
        import gpiod
        import spidev
        from gpiod.line import Direction, Value, Bias
        self.V = Value
        self.cs = [PINS[c][0] for c in COMPS]
        self.drdy = [PINS[c][1] for c in COMPS]
        self.req = gpiod.request_lines(GPIOCHIP, consumer='cmgcapture', config={
            tuple(self.cs): gpiod.LineSettings(direction=Direction.OUTPUT, output_value=Value.ACTIVE),
            tuple(self.drdy): gpiod.LineSettings(direction=Direction.INPUT, bias=Bias.PULL_UP)})
        self.spi = spidev.SpiDev()
        self.spi.open(0, 0)
        try:
            self.spi.no_cs = True
        except OSError:
            pass                        # Pi 5: CE0 on pin 24 toggles into thin air
        self.spi.mode = 1
        self.spi.max_speed_hz = speed
        self.conv_s = 0.0054            # measured in begin()
        self.t_done = 0.0

    def _xfer(self, cs, data):
        self.req.set_value(cs, self.V.INACTIVE)
        out = self.spi.xfer2(list(data))
        self.req.set_value(cs, self.V.ACTIVE)
        return out

    def begin(self):
        for cs in self.cs:
            self._xfer(cs, [RESET_CMD])
        time.sleep(0.002)
        for c, cs in zip(COMPS, self.cs):
            self._xfer(cs, [WREG | 3] + list(CONFIG))
            got = tuple(self._xfer(cs, [RREG | 3, 0, 0, 0, 0])[1:])
            if got != CONFIG:
                raise IOError("%s ADS1220 config readback %s, expected %s -- run ads_check.py"
                              % (c, ' '.join('%02X' % b for b in got),
                                 ' '.join('%02X' % b for b in CONFIG)))
        # time a few conversions: sets how long convert() sleeps before polling,
        # and the sample instant (the middle of the conversion)
        ts = []
        for _ in range(21):
            t = time.perf_counter()
            self.convert(sleep_first=False)
            ts.append(self.t_done - t)
        self.conv_s = sorted(ts)[len(ts) // 2]

    def _all_low(self):
        return all(v == self.V.INACTIVE for v in self.req.get_values(self.drdy))
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

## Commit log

2026-10-03 CMG-3T Digitizer And Control System: build document, Pi and PC software, printed box
    Three ADS1220s and an ADS1115 on two ElectroCookie boards, read by a
    Raspberry Pi 5 that also locks, unlocks and centres the masses of a
    Guralp CMG-3T. Includes the HTML build document, the capture daemon and
    mass control, the PC viewer and earthquake plots, the 3D-printed box,
    and photos.
    [box_base.stl, box_lid.stl, fit_test.stl]
2026-10-03 README: about the sensor (history, retirement, broadband performance)
2026-10-03 cmgclient: fixed y-label position so tick labels can't overlap them
    The layout was computed once on the first frame; when wider tick labels
    appeared later they ran into the channel labels. Labels now sit a fixed
    distance left of each axis, inside a fixed left margin.
2026-10-09 README: M6.3 Vanuatu example plots; PC earthquake alert with Telegram
    Three plots of the 2026-10-08 M6.3 Vanuatu quake (alert screenshots in the
    short period and 1-50 s views, cmgevent 10-100 s plot) with explanations.
    Also brings in the STA/LTA alert (cmgalert.py) and its settings.
    [loadOpts.py]
2026-10-09 README: M7.7 Panama example with labelled dark plots and spectrograms
    Replace the M6.3 Vanuatu example with the 2026-10-09 M7.7 Panama quake:
    Z/R/T traces with each wave type labelled and Z/T spectrograms showing
    surface-wave dispersion, in the 1-50 s and 10-100 s bands. Add
    pc/cmgwaves.py, which makes them. watch_cmg.py now runs one cmgevent.py
    at a time (the RUN lock was defined but never taken).
